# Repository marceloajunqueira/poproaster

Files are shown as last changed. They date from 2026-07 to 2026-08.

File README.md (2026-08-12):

# Pop Roaster

Um torrador de café caseiro feito em cima de uma pipoqueira elétrica de ar
quente, controlado por um ESP32-S3. A ideia é pegar um equipamento barato e
transformar ele num torrador de verdade, com controle de temperatura,
perfis de torra e acompanhamento em tempo real.

## BOM (lista de componentes)

| Item | Part Number | Link | Comentário | Preço |
|---|---|---|---|---|
| Pipoqueira | | [link](https://shopee.com.br/Pipoqueira-El%C3%A9trica-Super-Premium-1200W-Sem-%C3%93leo-Ar-Quente-i.389800143.22498754445) | | R$ 120,00 |
| Display | JC4827W543 | [link](https://pt.aliexpress.com/item/1005006729377800.html) | Selecionar Capacitive Touch | R$ 115,00 |
| SSR | SSR-40DA | [link](https://pt.aliexpress.com/item/1005005943909513.html) | | R$ 9,50 |
| PWM | XY-MOS | [link](https://pt.aliexpress.com/item/1005012364216704.html) | | R$ 3,36 |
| Termopar | MAX6675 | [link](https://pt.aliexpress.com/item/1005003841451196.html) | Selecionar Kit with probe | R$ 10,79 |
| Fonte | 24V 2A | [link](https://br.shp.ee/zNRZV278) | | R$ 19,90 |

## O que ele faz

- Tela touch no próprio equipamento com dashboard da torra ao vivo (BT, RoR, tempo).
- Dashboard também pelo navegador (Wi-Fi), com os mesmos controles.
- Perfis de torra configuráveis por segmento (tempo + temperatura + fan), com
  rampa de temperatura entre os segmentos (evita ficar "parado" num degrau).
- Controle de temperatura em malha fechada (PID) - você escolhe a
  temperatura, o firmware calcula a potência do aquecedor.
- Histórico das torras salvo no próprio equipamento, com gráfico de BT x tempo.
- Integração com o Artisan via Modbus TCP.
- Atualização de firmware por OTA (sem precisar abrir o equipamento).
- Camadas de segurança: corte automático por temperatura, watchdog de
  duração da torra, detecção de falha de sensor/ventoinha, etc.

Mais detalhes técnicos (build, pinagem, etc.) estão em
[`firmware/README.md`](firmware/README.md).

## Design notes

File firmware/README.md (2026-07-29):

# Pop Roaster Firmware

ESP-IDF firmware for the Pop Roaster coffee roaster controller, running on a
Guition JC4827W543 board (ESP32-S3-WROOM-1-N4R8, 480x272 NV3041A display,
GT911 capacitive touch). Provides an on-device touchscreen UI, a WiFi web
dashboard, Artisan roasting-software integration (Modbus TCP), roast
profile/preset management, session history, and OTA updates.

Full requirements/design docs live in
[`specs/001-pop-roaster-control/`](../specs/001-pop-roaster-control/)
(`spec.md`, `plan.md`, `tasks.md`, `quickstart.md`).

## Requirements

- ESP-IDF v6.0 (this project has not been tested against other major
  versions; several fixes in this codebase specifically address v6.0 API
  changes — see `/memories/repo/firmware-build-notes.md` if you have access
  to it, otherwise check git history of this file).
- Target chip: `esp32s3`.
- A Guition JC4827W543 board (or a board with the same NV3041A/GT911/pin
  layout — see `components/board_config/boards/board_jc4827w543.h`).

## Building and flashing

```powershell
cd firmware
idf.py set-target esp32s3
idf.py build
idf.py -p <PORT> flash monitor
```

If you are using the VS Code ESP-IDF extension, open the `firmware/` folder
directly as the workspace root (not the repo root) — the extension expects
`CMakeLists.txt`/`sdkconfig` at the workspace root.

Flash size is 4MB (`CONFIG_ESPTOOLPY_FLASHSIZE_4MB`, already set in
`sdkconfig.defaults`). Partition layout is defined in
[`partitions.csv`](partitions.csv): dual OTA app slots (`ota_0`/`ota_1`,
1.5MB each) plus a LittleFS `storage` partition (~896KB) for roast session
history.

## Hardware wiring

### Display & touch (fixed, on-board — no wiring needed)

The NV3041A display (QSPI) and GT911 touch controller (I2C) are soldered
directly to the JC4827W543 board. Pin assignments are fixed in
[`components/board_config/boards/board_jc4827w543.h`](components/board_config/boards/board_jc4827w543.h)
and are not user-configurable.

### External peripherals (user-wired via JST1.25 expansion connectors)

The board exposes 4 JST1.25 4-pin expansion connectors, but **this build
only uses 3 physical connectors** (P1, P2, P4) — P3 is left entirely
unused. Confirmed physical pinout:

| Connector | Pin 1 | Pin 2 | Pin 3 | Pin 4 | Used in this build? |
|---|---|---|---|---|---|
| P1 | GND | RXD | TXD | +5V | Power IN only (GND + +5V); RXD/TXD left unconnected |
| P2 | IO46 | IO9 | IO14 | IO5 | Yes — all 4 pins (MAX6675 x3 + SSR) |
| P3 | IO6 | IO7 | IO15 | IO16 | **Not used** (spare, only 3 connectors on hand) |
| P4 | GND | 3.3V | IO17 | IO18 | Yes — 3.3V/GND power OUT + fan MOSFET (IO18 spare) |

> **Note:** IO46 is **input-only** on the ESP32-S3 — it must never be
> assigned to an output signal (SSR, fan PWM/MOSFET). It is used by default
> for the MAX6675's read-only SO/MISO line.

Default GPIO assignments (configurable via `idf.py menuconfig` →
**Pop Roaster Board Configuration** → **External Peripheral GPIOs**, see
[`components/board_config/Kconfig`](components/board_config/Kconfig)):

| Signal | Default GPIO | Connector/pin | Notes |
|---|---|---|---|
| MAX6675 SCK (clock) | IO9 | P2, pin 2 | |
| MAX6675 CS (chip select) | IO14 | P2, pin 3 | |
| MAX6675 SO / MISO | IO46 | P2, pin 1 | Input-only pin, read-only signal — safe pairing |
| SSR heater control (on/off) | IO5 | P2, pin 4 | Drives a **40A SSR module** controlling the heating element; time-proportioning (duty cycle) is done in software over this single digital output |
| Fan MOSFET control (PWM) | IO17 | P4, pin 3 | Drives a fan motor **MOSFET module**; 20kHz default switching frequency (inaudible), LEDC timer 1 / channel 1 |

All 3 MAX6675 signals **plus** the SSR live on **P2** (fits exactly: 4
signals in a 4-pin connector). The fan MOSFET moved to **P4** alongside the
3.3V/GND power-out pins, which frees **P3 completely** — this build only
needs 3 physical JST1.25 connectors (P1 power-in, P2, P4) instead of 4.

Spare GPIOs not assigned by default (available for future peripherals, e.g.
fan RPM feedback): IO6, IO7, IO15, IO16 (all of unused P3), IO18 (P4).

> **Power note:** power the MAX6675 module from **3.3V** (available on P4,
> alongside GND), not 5V — its SO/MISO output logic level scales with its
> supply voltage, and the ESP32-S3's GPIOs are not 5V-tolerant. Running the
> sensor at 3.3V keeps the SO signal at a safe voltage for `IO46`.

### Wiring summary

```mermaid
graph LR
    ESP32S3["ESP32-S3<br/>(JC4827W543)"]
    MAX6675["MAX6675<br/>Thermocouple Amp"]
    SSR["40A SSR Module<br/>(heating element)"]
    FANPWM["Fan MOSFET Module<br/>(fan motor)"]

    ESP32S3 -- "P2: IO9 (SCK)" --> MAX6675
    ESP32S3 -- "P2: IO14 (CS)" --> MAX6675
    MAX6675 -- "P2: IO46 (SO/MISO)" --> ESP32S3
    ESP32S3 -- "P4: 3.3V/GND (power)" --> MAX6675

    ESP32S3 -- "P2: IO5 (on/off)" --> SSR
    ESP32S3 -- "P4: IO17 (PWM)" --> FANPWM
```

> **Safety:** the SSR and PWM modules switch mains-voltage/high-current
> loads (heating element, fan motor). Follow the module manufacturer's own
> isolation/wiring instructions, use appropriately rated wiring/connectors
> for the actual heater/fan current draw, and ensure proper enclosure and
> earthing. This firmware's software safety interlocks (below) are **not** a
> substitute for correct electrical installation.

## Software safety interlocks (summary)

See [`components/safety/safety_manager.c`](components/safety/safety_manager.c)
and `specs/001-pop-roaster-control/spec.md` for full details. Highlights:

- Fan speed is quantized to 5 discrete levels (Level 1-5 = 60/70/80/90/100%;
  Level 0 = off) - the motor doesn't behave predictably at arbitrary
  percentages; turning the fan on from a stop ramps smoothly over ~2s
  (soft start). The heater is only allowed on once the fan's REAL (live,
  interpolated) duty during that ramp has actually reached the floor, not
  just once the ramp was requested. Emergency Stop cuts the fan
  immediately, bypassing this.
- Heater requires fan ≥ Level 1 (60%) to be commanded on at all.
- Heater duty is additionally scaled by an operator-configurable "Max
  Heater Power" setting (Config tab, default 100%) - a linear proportional
  scale, not just a ceiling (e.g. at 50%, a requested 40% duty really only
  reaches 20%).
- Fan cannot be commanded to 0% while bean temperature ≥ 100°C (or the
  sensor reading is invalid — treated conservatively as "still hot").
- Sensor-failure detection forces the heater off.
- Duration watchdog auto-starts Cooling if a roast exceeds the configured
  maximum duration.
- Indirect fan-failure detection (anomalous rate-of-rise) forces the heater
  off and raises a critical alarm.
- Critical alarms require an explicit operator acknowledgement before any
  new heater command is accepted again.
- Emergency Stop (always visible on every screen/tab, and on the web
  dashboard) immediately cuts the heater and cancels the active session.

## Security considerations

This firmware is designed for a **trusted local network** (FR-021 in
`spec.md`): the web dashboard, Artisan Modbus TCP bridge, and OTA update
endpoint have **no authentication or transport encryption** (plain HTTP,
plain Modbus TCP). This is an explicit v1 design decision, not an oversight,
matching the project's "single-operator LAN appliance" scope. Concretely:

- **No login/auth on any web route** — anyone who can reach the device's IP
  on the local network can view telemetry, change fan/heater setpoints,
  start/cancel roasts, edit/delete presets, or trigger a firmware OTA
  upload. Do not expose this device's ports to the public internet (no port
  forwarding, no VPN-less remote access) — treat it like any other
  unauthenticated LAN appliance (e.g. a smart-home hub with no cloud
  account).
- **WiFi setup AP is open** (`WIFI_AUTH_OPEN`, in
  [`components/roaster_hal/wifi_provisioning.c`](components/roaster_hal/wifi_provisioning.c)) —
  it only exists transiently during initial provisioning; anyone in range
  could join it and submit different home-WiFi credentials during that
  window. Complete provisioning promptly after powering on a new device in
  an untrusted location.
- **Artisan Modbus TCP bridge** (`components/artisan_adapter/`) has no
  authentication either — any Modbus TCP client on the LAN can read
  telemetry registers, and (depending on mode) issue control writes. This
  mirrors how Artisan's own Modbus/serial integrations are normally used
  (a single roaster + a single laptop on the same bench network).
- **OTA firmware upload**
  ([`components/web_api/ota_routes.c`](components/web_api/ota_routes.c),
  [`components/roaster_hal/ota_manager.c`](components/roaster_hal/ota_manager.c)):
  any device on the LAN that can reach the web server can push a new
  firmware image. The uploaded image's integrity (magic bytes, header,
  checksum) is validated by `esp_ota_end()` **before** the boot pointer is
  switched to the new partition — a corrupt/incomplete/truncated upload is
  rejected and the device keeps running its current, known-good firmware.
  There is no cryptographic signature check on the image itself (ESP-IDF's
  Secure Boot / signed-app-image feature is not enabled in this project) —
  anyone who can reach the OTA endpoint can flash arbitrary firmware, not
  just an authentic Pop Roaster build. If you need to defend against a
  hostile actor on the same LAN (not just accidental misuse), evaluate
  enabling ESP-IDF Secure Boot + signed OTA images and/or putting the
  device on an isolated VLAN.
- **Recommended deployment**: keep the device on a home/workshop LAN behind
  a normal consumer router's NAT (no port forwarding), and treat the WiFi
  network itself (WPA2/WPA3 password) as the actual security boundary for
  this appliance — consistent with the constitution's stated trust model.

## Internationalization (i18n)

The on-device UI supports English (default), Portuguese, and Spanish via
compile-time string catalogs in
[`components/ui_display/i18n.c`](components/ui_display/i18n.c). Language
choice is switchable from **Config → Language** and persists across
reboots (NVS). Currently only the navigation sidebar and Config screen text
are localized end-to-end; a full per-screen retrofit of every remaining
label is not yet done (see `specs/001-pop-roaster-control/tasks.md` T055
notes).

## Artisan integration

See [`docs/artisan-integration.md`](docs/artisan-integration.md) for
step-by-step Artisan roasting-software setup instructions (Modbus TCP).

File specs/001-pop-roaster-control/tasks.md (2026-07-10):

---

description: "Task list for Pop Roaster Control Platform implementation"
---

# Tasks: Pop Roaster Control Platform

**Input**: Design documents from `specs/001-pop-roaster-control/`

**Prerequisites**: [plan.md](./plan.md), [spec.md](./spec.md), [research.md](./research.md), [data-model.md](./data-model.md), [contracts/](./contracts/), [quickstart.md](./quickstart.md)

**Tests**: Not explicitly requested in the feature specification; no dedicated test-first tasks are included. Manual/HIL validation is covered via quickstart.md in the Polish phase.

**Organization**: Tasks are grouped by user story (US1-US4, per spec.md priorities) to enable independent implementation and testing of each story.

## Format: `[ID] [P?] [Story] Description`

- **[P]**: Can run in parallel (different files, no dependencies)
- **[Story]**: Which user story this task belongs to (US1, US2, US3, US4)
- Include exact file paths in descriptions

## Path Conventions

Per [plan.md](./plan.md) Project Structure:

```text
firmware/
├── main/
├── components/
│   ├── board_config/
│   ├── roast_core/
│   ├── safety/
│   ├── hal/
│   ├── storage/
│   ├── ui_display/
│   ├── web_api/
│   └── artisan_adapter/
└── test/

webui/
└── src/
```

---

## Phase 1: Setup (Shared Infrastructure)

**Purpose**: Project initialization and basic structure

- [X] T001 Create firmware project skeleton (ESP-IDF) at firmware/ with main/ and components/ subfolders per plan.md
- [X] T002 Initialize ESP-IDF project dependencies via IDF Component Manager: `eric-c-e/esp_lcd_nv3041` (driver do painel NV3041A), `esp_lvgl_port` + LVGL, `esp_lcd_touch_gt911`, HTTP/WebSocket server, MAX6675 driver in firmware/main/idf_component.yml and firmware/main/CMakeLists.txt; register the already-created `board_config` component (firmware/components/board_config/)
- [X] T003 [P] Configure partition table with OTA A/B scheme in firmware/partitions.csv
- [X] T004 [P] Configure linting/formatting (clang-format) for firmware/
- [X] T005 [P] Scaffold webui/ static project structure (HTML/CSS/JS) in webui/src/

**Checkpoint**: Project scaffolding ready for foundational work

---

## Phase 2: Foundational (Blocking Prerequisites)

**Purpose**: Core infrastructure that MUST be complete before ANY user story can be implemented

**⚠️ CRITICAL**: No user story work can begin until this phase is complete

- [X] T006 Implement MAX6675 sensor driver in firmware/components/hal/max6675.c, reading pins from `BOARD_PERIPH_MAX6675_SCK_GPIO`/`BOARD_PERIPH_MAX6675_CS_GPIO`/`BOARD_PERIPH_MAX6675_SO_GPIO` (board_config.h) instead of hardcoded pin numbers
- [X] T007 [P] Implement SSR heater driver (time-proportioning control) in firmware/components/hal/ssr_heater.c, using `BOARD_PERIPH_SSR_HEATER_GPIO` (board_config.h)
- [X] T008 [P] Implement PWM fan driver in firmware/components/hal/fan_pwm.c, using `BOARD_PERIPH_FAN_PWM_GPIO`/`BOARD_PERIPH_FAN_PWM_LEDC_TIMER`/`BOARD_PERIPH_FAN_PWM_LEDC_CHANNEL`/`BOARD_PERIPH_FAN_PWM_FREQ_HZ` (board_config.h)
- [X] T009 [P] Implement NVS storage wrapper (profiles, calibration, network, language config) in firmware/components/storage/nvs_store.c
- [X] T010 [P] Implement LittleFS session history storage with circular retention (default 30 sessions) in firmware/components/storage/session_store.c
- [X] T011 Implement RoastSession state machine (IDLE→PREHEAT→ROASTING→DEVELOPMENT→COOLING→COMPLETED/ABORTED) in firmware/components/roast_core/session_state_machine.c (depends on T006-T008)
- [X] T012 Implement Safety Manager with hard-fail rules (30% fixed fan floor, heater-requires-fan, sensor-failure cutoff, absolute 260°C/240°C cutoff, duration watchdog hook, emergency stop hook, alarm ack gate) in firmware/components/safety/safety_manager.c (depends on T006-T008, T011)
- [X] T013 [P] Implement RoR (rate of rise) calculator utility in firmware/components/roast_core/ror_calculator.c
- [X] T014 [P] Implement DTR% calculator utility in firmware/components/roast_core/dtr_calculator.c
- [X] T015 Implement WiFi provisioning (AP mode + captive portal, then STA) in firmware/components/hal/wifi_provisioning.c
- [X] T016 Integrate GT911 touch controller via `esp_lcd_touch_gt911` using confirmed pins from board_config.h (SCL:4, SDA:8, RST:38, INT:3, addr 0x5D) in firmware/components/hal/touch_driver.c
- [X] T017 [P] Implement base HTTP/WebSocket server skeleton in firmware/components/web_api/server.c
- [X] T018 [P] Implement i18n string catalog loader (EN default, PT, ES) in firmware/components/ui_display/i18n.c

**Checkpoint**: Foundation ready - user story implementation can now begin

---

## Phase 3: User Story 1 - Torrar com segurança pelo display (Priority: P1) 🎯 MVP

**Goal**: Iniciar, acompanhar e finalizar uma torra pelo display com proteções automáticas de segurança.

**Independent Test**: Iniciar uma torra no display, aplicar ajustes manuais e concluir em resfriamento, validando as travas de segurança durante todo o ciclo.

### Implementation for User Story 1

- [X] T019 [US1] Implement command dispatcher wiring Safety Manager validation into fan/heater command handlers in firmware/components/roast_core/command_dispatcher.c (depends on T012)
- [X] T020 [US1] Implement operator-initiated pause/resume of an active roast (distinct from the power-loss auto-resume in T026) in firmware/components/roast_core/session_state_machine.c and firmware/components/roast_core/command_dispatcher.c (depends on T011, T019)
- [X] T021 [US1] Implement real-time telemetry dashboard screen (BT, RoR, DTR%, fan%, heater%, phase, timer) in firmware/components/ui_display/screens/roast_dashboard.c (depends on T013, T014, T019)
- [X] T022 [US1] Implement session history/review screen to browse and re-plot the BT+RoR curve of completed roast sessions on the display in firmware/components/ui_display/screens/session_review.c (depends on T010, T021)
- [X] T023 [P] [US1] Implement Emergency Stop widget (always-visible on display) in firmware/components/ui_display/widgets/emergency_stop_button.c (depends on T012) - implemented as a pinned button in the nav_shell sidebar (widgets/nav_shell.c) instead of a separate file, so it's visible on every tab, not just the dashboard
- [X] T024 [US1] Implement critical alarm banner with mandatory manual acknowledgment in firmware/components/ui_display/screens/alarm_banner.c (depends on T012) - implemented in widgets/nav_shell.c as a full-width banner pinned to the top of the screen (spans sidebar+content, visible on any tab), polling safety_manager_get_active_alarm() every 300ms and requiring an "ACK" tap (command_dispatcher_acknowledge_alarm) before it disappears
- [X] T025 [US1] Implement manual Cooling phase transition (heater forced off, fan stays on) in firmware/components/roast_core/session_state_machine.c (depends on T011) - REDESIGNED: no longer manually triggered by a dashboard button - Cooling is now entered automatically either via the profile's own trailing "Cooling" setpoint(s) (T038) or immediately when the operator taps Cancel/Emergency Stop (session_sm_cancel(), new function - heater off immediately, fan intentionally kept running rather than cut). New safety rule added to firmware/components/safety/safety_manager.c: the fan can never be commanded fully OFF (0%) while BT is at/above 100C (SAFETY_FAN_STOP_MIN_TEMP_C) or the sensor reading is invalid - protects the heating element/chamber from being left hot with no airflow now that Cooling duration/curve is profile-configurable
- [X] T026 [US1] Implement power-loss auto-resume with safety re-validation on boot in firmware/components/roast_core/session_recovery.c (depends on T011, T012)
- [X] T027 [US1] Implement max roast duration watchdog (default 25 min, forces auto-cooling) in firmware/components/safety/duration_watchdog.c (depends on T012)
- [X] T028 [US1] Implement indirect fan-failure detection via RoR anomaly pattern in firmware/components/safety/fan_failure_detector.c (depends on T012, T013)
- [X] T029 [US1] Implement Manual/Artisan control screen (direct fan/heater sliders, no curve) in firmware/components/ui_display/screens/manual_control.c (depends on T019) - implemented as a dedicated nav_shell tab ("Manual", replacing the "Presets" placeholder slot per user preference) with fan/heater sliders and live status readout
- [X] T062 [US1] Implement persistent left navigation shell (Material Design style, fixed sidebar with Roast/Presets/History/Config items, active-item highlight) in firmware/components/ui_display/widgets/nav_shell.c (depends on FR-045; replaces the current full-screen-replace navigation between roast_dashboard.c and session_review.c)
- [X] T063 [US1] Refactor roast dashboard to render inside the nav shell's content pane with a live BT+RoR timeline chart on top (drawn in real time as the roast progresses) and the phase/numeric readouts (BT, RoR, DTR%, fan%, heater%, timer) + Start Roast/Stop buttons in a compact row below, per approved sketch, in firmware/components/ui_display/screens/roast_dashboard.c (depends on T062, T021)
- [X] T064 [US1] Overlay the active profile's target BT curve on the live dashboard chart whenever the session is in Profile Mode in firmware/components/ui_display/screens/roast_dashboard.c (depends on T063, T030, T046 mode manager) - implemented (target BT AND Fan curves, dashed); now genuinely gated by Profile mode since Start Roast automatically starts ROAST_MODE_PROFILE whenever a preset is selected (T034)
- [X] T065 [US1] Render marked roast events (turning point, dry end, first/second crack, drop, etc.) as vertical reference markers on the chart, both on the live dashboard chart and on the session review chart, in firmware/components/ui_display/screens/roast_dashboard.c and session_review.c (depends on T056, T063, T022) - implemented: dashed purple vertical lines + short labels (child `lv_line`/`lv_label` objects, same technique as the target-curve overlay) drawn from `roast_events_get_all()` (live dashboard) / parsed `"ev"` lines in the session's `.jsonl` (session review), both rebuilt whenever the event list changes
- [X] T066 [US1] Wire the session history/review screen into the nav shell's content pane (History item) instead of a full-screen swap in firmware/components/ui_display/screens/session_review.c (depends on T062, T022)
- [X] T067 [P] [US1] Implement Config/Settings hub screen (Config item in nav shell) consolidating language switch, sensor calibration, peripheral test, and Wi-Fi setup entry points, per FR-046, in firmware/components/ui_display/screens/settings_hub.c (depends on T062) - implemented (2026-07-10) as a real menu replacing the placeholder: buttons into peripheral_test.c (T050) and sensor_calibration.c (T051), plus the device's own IP shown as `http://<ip>/wifi` and `http://<ip>/ota` links (Wi-Fi setup/reconfigure and firmware update are web-only, no on-device screens for those - T049 still not implemented on-device). Language switch UI still NOT implemented - blocked on T055 (i18n catalogs don't exist yet), shown as a "coming soon" note.

**Checkpoint**: User Story 1 fully functional and independently testable (manual roast start-to-finish with all safety interlocks)

---

## Phase 4: User Story 2 - Criar e usar perfis de torra (Priority: P1)

**Goal**: Criar perfis de torra com curvas interativas e reutilizá-los em novos lotes.

**Independent Test**: Criar um perfil no display, salvar, carregar em nova sessão e verificar execução guiada por curva.

### Implementation for User Story 2

- [X] T030 [P] [US2] Implement RoastProfile model and CRUD logic in firmware/components/roast_core/roast_profile.c - model + piecewise-linear target BT/Fan curve interpolation implemented; full CRUD (create/edit/duplicate-via-"+ Add Segment"/delete) now available from the UI via the profile editor screen (T032)
- [X] T031 [US2] Implement profile persistence in NVS (create/update/delete/list) in firmware/components/storage/profile_store.c (depends on T009, T030); on NVS full or corrupted profile data, reject the write/read with a clear error surfaced to the UI instead of silently corrupting or losing other stored profiles - list/load/select-active/create/update/delete all implemented and persisted in NVS (profile_store_create/update/delete added for T032); deleting the currently-selected profile clears the selection; corrupted/oversized blob reads are rejected (size-mismatch check) but not yet surfaced as a UI-visible error message (logged only)
- [X] T032 [US2] Implement profile editor screen combining read-only curve graph with editable numeric point table in firmware/components/ui_display/screens/profile_editor.c (depends on T030) - implemented as a numeric point-table editor (no interactive curve-DRAWING graph - the read-only dashed target curve is already viewable on the Roast dashboard/Roast History once a profile is selected/run, T033/T064): each segment is an editable "card" (duration mm:ss, target BT, target fan%, target heater%, Cooling toggle, all via +/- steppers in 15s/5C/5%/5% increments) with Add/Delete Segment, Save, Delete Profile, and tap-to-rename (lv_textarea + lv_keyboard overlay) - reachable from the Presets tab (profile_list.c) via a "+ New" button or a per-profile "Edit" button. **UPDATE (2026-07-10)**: web parity added - `web_api/presets_routes.c` gained `GET /presets/edit?id=N` (N=-1 for a brand-new profile), `POST /api/presets/save` (create or update, name + a client-side-managed list of duration/temp/fan/cooling segment rows, re-serialized with fresh sequential indices on every save so removing a middle row never leaves a gap), and `POST /api/presets/delete` - same fan-floor (30%) and fixed-Cooling-values (0C/100%) server-side invariants as the display editor. Web presets page ("/presets") now has a "+ New Profile" button and an "Edit" link per row instead of being read-only/select-only.
- [X] T033 [US2] Implement profile list/selection screen in firmware/components/ui_display/screens/profile_list.c (depends on T031) - lists stored profiles, tap to mark one as selected (persisted) for the next roast on the Roast tab; the Roast dashboard chart plots its target BT/Fan curves (dashed) against the live measured values (solid) and its name in the corner
- [X] T034 [US2] Implement Profile-mode curve-following control loop (targetFanPct/targetHeaterPct per curve point, respecting 30% floor) in firmware/components/roast_core/profile_curve_follower.c (depends on T011, T012, T030) - implemented: a 1s esp_timer drives command_dispatcher_set_fan_pct/set_heater_pct from the selected profile's per-segment target_fan_pct/target_heater_pct (added to roast_profile_point_t) whenever the session is ROAST_MODE_PROFILE and past CHARGE (ROASTING/DEVELOPMENT); target_temp_c remains a visual-only reference (no closed-loop BT control). Start Roast on the dashboard now starts in ROAST_MODE_PROFILE automatically when a preset is selected (else falls back to MANUAL_ARTISAN)
- [X] T035 [US2] Implement manual override during Profile mode (persists until next curve point, then profile resumes) in firmware/components/roast_core/profile_curve_follower.c (depends on T034) - detects a manual fan/heater change (actual value differs from what the follower itself last wrote) and backs off until roast_profile_get_segment_index() crosses into the next setpoint segment, then resumes automatic control
- [X] T036 [US2] Implement preheat-ready visual signal and CHARGE event confirmation gate in firmware/components/ui_display/screens/preheat_ready_banner.c (depends on T034) - implemented as a minimal "Charge" button directly in roast_dashboard.c (not a separate file) shown during PREHEAT; tapping it calls the new session_sm_confirm_charge()/command_dispatcher_confirm_charge(), transitioning PREHEAT->ROASTING and resetting the elapsed-time reference so the roast clock/curve/chart timeline starts counting from CHARGE (not from Start Roast); NOTE: no smart "preheat-ready" temperature-based visual signal yet (button is always tappable during PREHEAT, not gated on reaching a target preheat temperature) - this was a pre-existing gap (nothing previously transitioned PREHEAT->ROASTING at all) fixed as a byproduct of unblocking T034
- [X] T037 [US2] Implement profile snapshot capture into RoastSession at session start in firmware/components/roast_core/session_state_machine.c (depends on T011, T030) - implemented as session_meta_t (storage/session_store.h: roast number + full profile snapshot) saved via session_store_save_meta() in roast_core/roast_telemetry_service.c's roast_telemetry_service_on_roast_started(), rather than inside session_state_machine.c itself; Roast History (session_review.c) loads this snapshot to redraw the exact target curve that was active during that specific roast, unaffected by later profile changes/deletions (FR-034)
- [X] T038 [US2] Implement automatic Cooling transition via profile drop point in firmware/components/roast_core/profile_curve_follower.c (depends on T034) - REDESIGNED per operator feedback: Cooling is no longer a separate manual button/step - it's now one or more trailing setpoints in the profile itself (`roast_profile_point_t.is_cooling`, heater forced to 0%, fan/duration configured like any other setpoint), so the cooldown curve shows up on the chart exactly like the rest of the roast. profile_curve_follower.c auto-transitions ROASTING/DEVELOPMENT->COOLING the moment the curve enters an is_cooling segment, keeps driving ONLY the fan from that segment's curve (never the heater), and auto-finalizes (session_sm_complete()) once the profile's full timeline elapses, BT drops below a safe threshold, or a 15-minute failsafe elapses (whichever comes first) - no manual "Start Cooling"/"Complete" button exists anymore
- [X] T039 [P] [US2] Implement profile export (JSON) endpoint in firmware/components/web_api/routes/profiles_export.c (depends on T031) - implemented as `GET /api/presets/export?id=N` in `firmware/components/web_api/presets_routes.c` (not a separate `routes/` subfolder file, same flat-file convention as every other web_api route): outputs a compact `{"name":...,"points":[[dur,temp,fan,cooling],...]}` JSON with a `Content-Disposition: attachment` download header; also has an "Export" link per row on the web presets list page
- [X] T040 [P] [US2] Implement profile import (JSON upload) endpoint in firmware/components/web_api/routes/profiles_import.c (depends on T031) - implemented as `POST /api/presets/import` in `presets_routes.c`: manual `strstr`/`sscanf`-based parser (no cJSON dependency, matching this project's existing manual-parsing convention) for the same export format, with a client-side `FileReader`+`fetch()` file-upload widget on the presets page; same value clamps (fan floor, cooling fixed values) as the manual editor's save handler

**Checkpoint**: User Stories 1 AND 2 both work independently

---

## Phase 5: User Story 3 - Monitorar por web e integrar com Artisan (Priority: P2)

**Goal**: Acompanhar a torra por navegador e integrar com o Artisan (bidirecional, gated por modo).

**Independent Test**: Iniciar uma torra e validar que os mesmos dados/comandos estão disponíveis no display e na web, e que os dados chegam ao Artisan conforme o modo ativo.

### Implementation for User Story 3

- [X] T041 [P] [US3] Implement WebSocket telemetry broadcast (BT, RoR, DTR%, phase, controlMode) in firmware/components/web_api/ws_telemetry.c (depends on T017) - implemented in firmware/components/web_api/dashboard_routes.c (not a separate ws_telemetry.c file) instead: a 1s esp_timer broadcasts a JSON telemetry frame (phase, mode, paused, elapsedMs, bt, sensorValid, ror, dtr, fan, heater, alarmText, alarmNeedsAck) to every connected client on "/ws/telemetry" via httpd_ws_send_frame_async(); CONFIG_HTTPD_WS_SUPPORT enabled in sdkconfig.defaults (was off by default)
- [X] T042 [US3] Implement web control command endpoint with last-write-wins across display/web/Artisan in firmware/components/web_api/routes/control_command.c (depends on T012, T019) - implemented as POST /api/control in dashboard_routes.c (not a separate routes/ subfolder file): form-encoded body "action=xxx&value=NN", dispatches set_fan/set_heater/pause/resume/cancel/emergency_stop/ack_alarm/confirm_charge/start through command_dispatcher.h with SAFETY_CMD_SOURCE_WEB, so it automatically gets the same last-write-wins arbitration and Profile-mode-Artisan-read-only gate as every other source
- [X] T043 [P] [US3] Implement web dashboard page (real-time BT+RoR chart, controls) in webui/src/dashboard.html and webui/src/dashboard.js (depends on T041) - implemented as an inline-generated page (dashboard_routes_send_page() in dashboard_routes.c, served at "/" once WiFi is connected, replacing the old simple status card) instead of static files under webui/src/ (webui/src/index.html remains an unused placeholder from T005) - same self-contained/no-CDN convention as wifi_setup_routes.c's existing pages (FR-021: must work fully offline); chart is a plain <canvas> 2D rolling-window plot (last 300 samples \u2248 5min, BT+Fan only, not yet BT+RoR as the task title says, and not yet matched 1:1 to the profile's target-curve timeline like the display's chart - a reasonable future refinement) fed by the T041 WebSocket stream; includes Fan/Heater override sliders, Start Roast/Charge/Pause-Resume/Cancel buttons mirroring the display's phase-based button groups. ALSO added (beyond the original task scope, for web/display navigation parity): a shared nav bar (Dashboard/Roast History/Presets/Wi-Fi Setup) plus two new pages - GET /history (+/history/detail, mirroring session_review.c's list+detail, stats + a simple actual-only BT/Fan chart, no target-curve overlay yet) and GET /presets (+POST /api/presets/select, read-only preset picker mirroring profile_list.c's selection behavior - no web-side profile editor, use the display's Presets tab for CRUD, T032). **UPDATE (2026-07-10)**: web-side preset create/edit/delete was added after all (GET /presets/edit, POST /api/presets/save|delete in presets_routes.c) - see T032's note. Also (2026-07-10): the shared stylesheet was extracted from an inline `<style>` block re-sent on every page into its own cached `GET /style.css` route (`Cache-Control: public, max-age=86400`) via a new `WEB_UI_STYLE_LINK` macro - the repeated multi-KB inline CSS on every navigation was a real contributor to "the web UI feels slow"
- [X] T044 [US3] Implement Emergency Stop control on the web dashboard, mirroring the display widget (T023) so it is always visible and accessible from both surfaces per FR-027, in webui/src/dashboard.html and webui/src/dashboard.js (depends on T012, T043) - a prominent always-visible "EMERGENCY STOP" button (with a JS confirm() prompt to avoid accidental taps, unlike the display's version which has no confirmation - worth reconsidering for consistency later) posts action=emergency_stop
- [X] T045 [US3] Implement critical alarm banner with mandatory manual acknowledgment on the web dashboard, mirroring the display behavior (T024) so alarm ack has web/display parity, in webui/src/dashboard.html and webui/src/dashboard.js (depends on T012, T043) - a full-width red banner (shown/hidden per the WS stream's alarmNeedsAck flag) with the human-readable alarm text (mirroring nav_shell.c's alarm_text() wording) and an ACK button posting action=ack_alarm
- [X] T046 [US3] Implement Mode Manager (Profile vs Manual/Artisan, one-way irreversible switch with confirmation) in firmware/components/roast_core/mode_manager.c (depends on T011, T034) - the underlying transition (session_sm_switch_to_manual_artisan(), irreversible, mode_switch_used latch) already existed from earlier work; this task added the missing piece - an actual operator-facing trigger: command_dispatcher_switch_to_manual_artisan(confirmed, source) wrapper + a "Switch to Manual" button on the WEB dashboard (dashboard_routes.c), shown only while an active PROFILE-mode session is running, gated behind a JS confirm() dialog before posting action=switch_manual&value=1; NOTE: no equivalent button exists on the DISPLAY side yet (roast_dashboard.c) - web-only for now, a gap worth closing later for display/web parity
- [X] T047 [US3] Implement Artisan serial/TCP adapter (telemetry always published; commands accepted only in Manual/Artisan mode) in firmware/components/artisan_adapter/artisan_bridge.c (depends on T042, T046) - implemented as a Modbus TCP slave (port 502), confirmed as Artisan's own real network-capable device protocol by reading Artisan's source (artisanlib/modbusport.py: `AsyncModbusTcpClient`, per-channel host/port/device-id/register/function-code config) - no serial/USB cable or extra PC-side software needed, works over the same WiFi the device already uses. Uses `espressif/esp-modbus` v2.x (idf_component.yml pinned `^2.1`; the older v1.x line uses the legacy `driver/timer.h`/`driver/uart.h` headers ESP-IDF v6.0 removed/split out, so v1.x fails to compile on this project's IDF version - v2.x's port implementation doesn't have this problem). Register map (plain 16-bit Holding Registers, slave id 1, scaled-integer convention chosen specifically to avoid any float/word-order ambiguity - see the header doc comment for the exact Artisan per-channel Div/Signed settings to use): reg 0 = BT x10, reg 1 = Fan %, reg 2 = Heater %, reg 3 = RoR x10 (signed); reg 100/101 = Set Fan %/Set Heater % (writable - a background poll task applies new values via command_dispatcher.h with SAFETY_CMD_SOURCE_ARTISAN, which already silently ignores Artisan commands while ROAST_MODE_PROFILE is active per the pre-existing Profile-mode-Artisan-read-only gate, so no new mode-gating logic was needed). No build/CMakeLists patches needed - v2.x's own CMakeLists.txt already correctly requires `esp_driver_uart` for IDF >5.2.
- [X] T048 [P] [US3] Implement session export endpoint (CSV and .alog formats) in firmware/components/web_api/routes/sessions_export.c (depends on T010) - implemented as GET /api/sessions/export?id=...&format=csv in firmware/components/web_api/history_routes.c (not a separate routes/ subfolder file): streams the session's .jsonl telemetry as a CSV (t_ms,bt_c,ror_c_per_min,fan_pct,heater_pct,phase) via chunked response with a Content-Disposition download header; .alog (Artisan) format NOT yet implemented - deferred until T047's Artisan bridge exists and there's a concrete format to validate against
- [X] T049 [US3] Implement WiFi AP + captive portal setup screen and web page in firmware/components/ui_display/screens/wifi_setup.c and webui/src/wifi_setup.html (depends on T015) - on-device screen implemented (`ui_display/screens/wifi_setup.c`/`.h`, manual SSID/password entry via the standard textarea+keyboard overlay pattern, reachable from Config → Wi-Fi Setup); the web side (`wifi_setup_routes.c`) already existed from earlier work. No DNS-based captive-portal auto-popup on phones (operator must browse to 192.168.4.1 manually while joined to the setup AP), same as before - not a regression, just not newly added here

**Checkpoint**: User Stories 1, 2, AND 3 all independently functional

---

## Phase 6: User Story 4 - Validar hardware e manutenção (Priority: P3)

**Goal**: Tela de teste de periféricos e atualização de firmware por upload web.

**Independent Test**: Acionar testes individuais de sensor/ventilação/aquecimento e realizar upload de firmware com confirmação de sucesso.

### Implementation for User Story 4

- [X] T050 [P] [US4] Implement peripheral test screen (sensor/fan/heater individual tests, confirmation required before heater test) in firmware/components/ui_display/screens/peripheral_test.c (depends on T006-T008, T012) - live sensor readout (reads max6675_read() directly) + a bounded Fan test (50%/5s, tap again to cancel early) + a Heater test gated behind a two-tap "Confirm?" pattern (same as session_review.c's Delete All) that auto-raises the fan to the 30% safety floor first, runs the heater at a low 20% test duty for 8s, and always force-stops (heater then fan to 0) when the screen is left via Back OR a tab switch away - never leaves a test running unattended
- [X] T051 [P] [US4] Implement sensor calibration UI and offset persistence in firmware/components/ui_display/screens/sensor_calibration.c (depends on T009) - live reading + current offset readout, a +/-1C reference-temperature stepper (default 100C, e.g. boiling water), and an "Apply" button that computes the offset needed to make the next reading equal the chosen reference (persisted via the already-existing hal/max6675.h calibration offset API, NVS-backed) plus a "Reset offset to 0" button
- [X] T052 [US4] Implement firmware upload endpoint with A/B partition OTA (validate, install to secondary partition, switch boot only on success) in firmware/components/web_api/ota_routes.c (depends on T009) - deviates from the literal `web_api/routes/firmware_upload.c` path the same way every other web_api route file in this project already does (flat file, not a routes/ subfolder); POST /api/ota/upload streams the raw firmware binary body (via repeated httpd_req_recv() into a static scratch buffer) into hal/ota_manager.c, which only switches the boot partition after esp_ota_end() validates the image - a corrupt/incomplete upload leaves the current firmware completely untouched
- [X] T053 [US4] Implement OTA status endpoint and rollback-safe boot logic (stay on current partition on any failure) in firmware/components/roaster_hal/ota_manager.c (depends on T052) - deviates from the literal `hal/ota_manager.c` path only in that the `hal` component was renamed `roaster_hal` earlier in this project (see firmware-build-notes memory); GET /api/ota/status (JSON: version/partition/pendingVerify) implemented in ota_routes.c; relies on the already-enabled `CONFIG_BOOTLOADER_APP_ROLLBACK_ENABLE=y` - ota_manager_init() (called near the end of app_main(), after the display/web server have already come up successfully) calls esp_ota_mark_app_valid_cancel_rollback() only if the running image is still PENDING_VERIFY, so a crash-loop right after an update auto-reverts to the previous known-good partition with zero custom logic needed for that part - it's the standard ESP-IDF app-rollback mechanism
- [X] T054 [P] [US4] Implement firmware update web page (file upload UI) in webui/src/firmware_update.html (depends on T052) - implemented as an inline-generated page (GET /ota in ota_routes.c, same no-external-CDN convention as dashboard/history/presets/diagnostics routes) instead of a static webui/src/ file; plain `<input type=file>` + XMLHttpRequest upload with a live progress percentage, auto-reloads 15s after a reported success to show the new running version. Added a "Firmware Update" nav bar entry (dashboard_routes.c) and a reachable entry point from the display's Config tab (new `ui_display/screens/settings_hub.c`, T067-adjacent - shows the device's own IP + /ota and /wifi links since the actual upload/setup UI itself is web-only) - also wired the previously-orphaned T050/T051 display screens in via that same settings hub, replacing the old Config tab placeholder

**Checkpoint**: All user stories (US1-US4) independently functional

---

## Phase 7: Polish & Cross-Cutting Concerns

**Purpose**: Improvements that affect multiple user stories

- [X] T055 [P] Create i18n string catalogs (en.json, pt.json, es.json) and language switch UI in firmware/components/ui_display/i18n/ and webui/src/i18n/ (depends on T018) - implemented as compile-time C string-array catalogs (`ui_display/i18n.c`: `kStringsEn/Pt/Es[]`, not JSON files) with a persisted (NVS) language choice and a Language button on the Config screen (cycles EN→PT→ES→EN); `nav_shell_refresh_labels()` live-updates the sidebar text immediately on switch. **Honest scope note**: only the nav sidebar and the Config screen's own text are i18n-driven end-to-end; a full per-screen retrofit of every remaining label (dashboard, manual control, profile editor, history, web UI) was NOT done - a real, deliberate scope reduction, not an oversight (see `firmware/docs/quickstart-desk-check.md` Cenário 8 for the honest caveat)
- [X] T056 [P] Implement RoastEvent milestone marking UI (charge, turning point, dry end, first/second crack, drop, cool start, manual note) in firmware/components/ui_display/screens/event_markers.c - implemented as a new `roast_core/roast_events.c`/`.h` (event list + persistence via `roast_telemetry_service_record_event()`) plus a "Mark Event" button + full-screen 9-button overlay directly in `roast_dashboard.c` (not a separate `event_markers.c` screen file) - marking FC Start also auto-triggers the existing DTR-calculator's first-crack timestamp
- [X] T057 [P] Implement BatchRecord metadata form (coffee name, origin, weight, notes) in firmware/components/ui_display/screens/batch_metadata.c - implemented as a `batch_record_t` (storage/session_store.h, embedded in `session_meta_t`) filled in via a "Batch Info" button + overlay directly in `roast_dashboard.c` (not a separate `batch_metadata.c` file) while idle, applied to the session's metadata at roast start; displayed back in Roast History's session detail view (`session_review.c`) whenever any field was filled in
- [X] T058 Security review pass: confirm no-auth/trusted-network assumptions are documented in README, validate firmware upload checksum verification - added a "Security Considerations" section to `firmware/README.md` documenting the FR-021 no-auth/trusted-LAN assumption across the web dashboard, WiFi setup AP, Artisan Modbus bridge, and OTA upload endpoint, plus the lack of firmware image signature verification (Secure Boot not enabled); confirmed `esp_ota_end()` (`roaster_hal/ota_manager.c`) already validates image integrity (magic bytes/header/checksum) before switching the boot partition - no code change was needed for that part, just documenting it
- [X] T059 [P] Performance tuning: ensure telemetry/chart updates sustain 2-5 Hz without UI stutter on JC4827W543 - `roast_telemetry_service.c` already sampled at 500ms (2Hz); the on-device dashboard's own `lv_timer` already refreshed at 500ms (2Hz); the one gap found was the WEB dashboard's WebSocket broadcast timer (`dashboard_routes.c`), previously 1000ms (1Hz, below the 2-5Hz target) - bumped to 500ms (2Hz) so web clients now see updates exactly as often as the physical display. No real-hardware profiling was performed (not possible in this environment) - this is a code-review-based cadence adjustment; UI stutter itself was not measured on device
- [X] T060 Run quickstart.md validation end-to-end (all 9 scenarios in specs/001-pop-roaster-control/quickstart.md) - performed as a static "desk check" only (see `firmware/docs/quickstart-desk-check.md`): every scenario/step cross-referenced against the actual implementing code path by reading the source, NOT executed on a powered roaster (requires real heating element/sensor/fan hardware this environment doesn't have). 5 honest gaps were found and documented (no on-device Manual-mode-switch trigger, no `.alog` export, partial i18n coverage, unverified DTR/RoR numerical correctness, unverified Artisan event-register exposure) - none safety-critical, all require real hardware/Artisan to close out. The operator should still run the actual 8 scenarios on real hardware before considering this fully validated
- [X] T061 [P] Documentation: update README with hardware wiring (SSR 40A, PWM 15A, MAX6675) and setup instructions - created `firmware/README.md` (none existed before) covering build/flash instructions, the JST1.25 expansion connector pinout + default GPIO assignments (from `board_config/Kconfig`) for MAX6675/SSR/fan, a wiring diagram, a summary of the software safety interlocks, the Security Considerations section (T058), i18n status, and a link to the existing Artisan integration doc

---

## Dependencies & Execution Order

### Phase Dependencies

- **Setup (Phase 1)**: No dependencies - can start immediately
- **Foundational (Phase 2)**: Depends on Setup completion - BLOCKS all user stories
- **User Story 1 (Phase 3)**: Depends on Foundational completion - no dependency on other stories
- **User Story 2 (Phase 4)**: Depends on Foundational completion - independent of US1, but profile-mode control loop (T034) shares command dispatcher patterns from US1
- **User Story 3 (Phase 5)**: Depends on Foundational completion and on Mode Manager needing US2's profile curve follower (T034) to distinguish Profile vs Manual/Artisan
- **User Story 4 (Phase 6)**: Depends on Foundational completion - independent of US1/US2/US3
- **Polish (Phase 7)**: Depends on all desired user stories being complete

### User Story Dependencies

- **User Story 1 (P1)**: Can start after Foundational (Phase 2) - No dependencies on other stories
- **User Story 2 (P1)**: Can start after Foundational (Phase 2) - Independently testable; shares command dispatcher from US1 conceptually but has its own control loop
- **User Story 3 (P2)**: Can start after Foundational (Phase 2) - Integrates with US1 (command dispatcher, Emergency Stop, alarm ack) and US2 (profile curve follower) for Mode Manager and web/display parity, but web dashboard/telemetry itself is independently testable
- **User Story 4 (P3)**: Can start after Foundational (Phase 2) - Fully independent of US1/US2/US3

### Parallel Opportunities

- All Setup tasks marked [P] (T003-T005) can run in parallel
- Foundational tasks marked [P] (T007-T010, T013-T014, T017-T018) can run in parallel within Phase 2; T016 (GT911 touch integration) can run in parallel with the other foundational tasks
- Once Foundational completes, US1, US2, and US4 can be worked on in parallel by different developers; US3 benefits from US1/US2 being further along but can start in parallel with careful stubbing
- Within US1: T023 (Emergency Stop widget) can run in parallel with T021/T024-T029; T020 (pause/resume) and T022 (session review screen) can be developed in parallel with each other once T019/T021 are ready
- Within US2: T030 parallel with foundational work; T039-T040 (profile export/import) parallel with each other
- Within US3: T041 and T043 can run in parallel; T044 and T045 (web Emergency Stop / alarm ack) can run in parallel with each other once T043 is ready; T048 parallel with T041-T047
- Within US4: T050, T051, T054 can run in parallel with each other

---

## Parallel Example: User Story 1

```bash
# After T019 (command dispatcher) is done, these can run in parallel:
Task: "Implement Emergency Stop widget in firmware/components/ui_display/widgets/emergency_stop_button.c"
Task: "Implement critical alarm banner in firmware/components/ui_display/screens/alarm_banner.c"
Task: "Implement indirect fan-failure detection in firmware/components/safety/fan_failure_detector.c"
Task: "Implement operator-initiated pause/resume in firmware/components/roast_core/session_state_machine.c"
```

## Parallel Example: User Story 2

```bash
Task: "Implement profile export (JSON) endpoint in firmware/components/web_api/routes/profiles_export.c"
Task: "Implement profile import (JSON upload) endpoint in firmware/components/web_api/routes/profiles_import.c"
```

## Parallel Example: User Story 3

```bash
# After T043 (web dashboard page) is done, these can run in parallel:
Task: "Implement Emergency Stop control on the web dashboard"
Task: "Implement critical alarm banner with manual acknowledgment on the web dashboard"
```

---

## Implementation Strategy

### MVP First (User Story 1 Only)

1. Complete Phase 1: Setup
2. Complete Phase 2: Foundational (CRITICAL - blocks all stories, includes Safety Manager and GT911 touch integration)
3. Complete Phase 3: User Story 1 (Manual/Artisan roast with full safety interlocks)
4. **STOP and VALIDATE**: Run Cenário 1 and Cenário 2 (partial) from quickstart.md
5. Deploy/demo if ready — this is a safe, usable torrador even without profiles yet

### Incremental Delivery

1. Complete Setup + Foundational → Foundation ready (drivers, safety manager, storage, touch/GT911 integrated)
2. Add User Story 1 → Test independently → Deploy/Demo (MVP: safe manual roasting)
3. Add User Story 2 → Test independently → Deploy/Demo (repeatable profiles)
4. Add User Story 3 → Test independently → Deploy/Demo (web UI + Artisan, with web/display safety parity)
5. Add User Story 4 → Test independently → Deploy/Demo (maintenance/OTA)
6. Polish phase → i18n, event markers, batch metadata, quickstart full validation

### Parallel Team Strategy

With multiple developers:

1. Team completes Setup + Foundational together (Safety Manager is the critical path — prioritize it)
2. Once Foundational is done:
   - Developer A: User Story 1 (display safety flow)
   - Developer B: User Story 2 (profiles)
   - Developer C: User Story 4 (peripheral tests/OTA) — fully independent
   - User Story 3 (web/Artisan) starts once US1's command dispatcher/Emergency Stop/alarm ack and US2's curve follower have stable interfaces
3. Stories complete and integrate independently

---

## Notes

- [P] tasks = different files, no dependencies
- [Story] label maps task to specific user story for traceability
- Safety Manager (T012) is the single most critical foundational task — all hard-fail rules (30% fan floor, 260°C/240°C cutoff, watchdog, emergency stop, alarm ack) route through it
- Touch controller is confirmed as GT911 (I2C) with pins already defined in `firmware/components/board_config/boards/board_jc4827w543.h` — T016 is a direct integration task, not a discovery task
- Web dashboard now has explicit parity tasks for Emergency Stop (T044) and alarm acknowledgment (T045), matching the display-side widgets (T023, T024) per FR-027/FR-012
- No dedicated test-first tasks were generated (not requested in spec); quickstart.md scenarios (T060) serve as the acceptance validation pass
- Commit after each task or logical group
- Stop at any checkpoint to validate story independently

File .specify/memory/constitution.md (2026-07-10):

# Pop Roaster Constitution

## Core Principles

### I. Safety-First, Non-Negotiable
Every command that can affect the heater or fan (from display, web, or Artisan) MUST pass through a single, centralized Safety Manager before being applied — no UI, network client, or external integration may bypass it. Hard-fail rules (minimum ventilation floor, absolute temperature cutoff, sensor-failure cutoff, indirect fan-failure detection, maximum roast duration watchdog, dedicated Emergency Stop) are always enforced regardless of operating mode. Critical alarms MUST require explicit manual acknowledgment before the roast can continue. Any relaxation of a safety rule requires an explicit, documented decision (via `/speckit.clarify`) and must be recorded as a residual risk if accepted, never silently assumed.

### II. Domain/Interface Separation
Business logic (roast state machine, safety rules, profile curve following, RoR/DTR calculation) MUST NOT depend on any specific display, web framework, or external protocol. All hardware-specific details (pins, display driver, touch controller) are isolated behind a `board_config` contract so new boards/displays can be added by implementing that contract, without modifying `roast_core/`, `safety/`, or business rules elsewhere.

### III. Configuration Over Hardcoding
Hardware wiring that can vary between physical builds (external peripheral GPIOs for sensors/actuators wired via expansion connectors) MUST be configurable (e.g., via Kconfig/menuconfig) rather than hardcoded, so the same firmware source supports rewiring without code changes. Fixed, board-soldered hardware (the display panel and its touch controller) is defined once per board profile and treated as immutable for that board.

### IV. Data Integrity and Continuity
User-created data (roast profiles, roast session history, calibration) MUST survive power loss, reboots, and — where explicitly decided — deletion of related records (e.g., a session keeps its own snapshot of the profile used, independent of the profile's later deletion). Firmware updates MUST use a safe scheme (A/B partitions) where failure never leaves the device in a non-functional state. Users MUST be able to export/import their own data (profiles, sessions) independent of the device.

### V. Spec-Driven Development
All functional ambiguity MUST be resolved through the `/speckit.clarify` workflow and recorded in `spec.md` before or during planning — decisions are not to be assumed silently by whoever implements them. The standard flow for this project is: `/speckit.specify` → `/speckit.clarify` → `/speckit.plan` → `/speckit.tasks` → `/speckit.analyze` → `/speckit.implement`. Significant scope changes discovered mid-flow (e.g., new hardware facts, new safety considerations) require re-running the affected steps rather than patching artifacts inconsistently.

## Security & Trust Boundaries

The v1 scope explicitly trusts the local network the device is connected to: there is no authentication for the web interface, control commands, or firmware upload. This is a deliberate, documented trade-off for a single-user, home/workshop-network context — not an oversight. Any future work that exposes the device beyond a trusted local network (e.g., remote/cloud access) MUST revisit this principle explicitly via `/speckit.clarify` before being implemented, since the current design assumes physical/network isolation as the only access control.

Known accepted residual risks (documented in `spec.md` Assumptions) MUST remain visible there and MUST NOT be quietly removed without an explicit decision to mitigate or formally re-accept them.

## Development Workflow

- Every feature starts with a specification (`spec.md`) covering user stories, functional requirements, success criteria, and edge cases before any implementation planning begins.
- `/speckit.analyze` MUST be run after `/speckit.tasks` and before `/speckit.implement` to catch coverage gaps, inconsistencies, and drift between spec/plan/tasks; CRITICAL findings block implementation, MEDIUM/LOW findings are remediated or explicitly accepted by the user.
- Hardware facts (pinouts, chip models, module variants) MUST be grounded in verifiable sources (vendor documentation, component registries, physically confirmed pin tests) before being written into `research.md`/`plan.md`/board configuration files — assumptions must be clearly labeled as such until confirmed.
- Tests are optional per feature and only added when explicitly requested; when omitted, the `quickstart.md` scenarios serve as the acceptance validation pass before considering a feature done.

## Governance

This constitution supersedes ad-hoc practices for this project. Amendments require an explicit update to this file (via `/speckit.constitution` or direct edit) with a version bump and a note of what changed and why. All specs, plans, and tasks for this project should be checked against these principles during `/speckit.analyze`; any conflict is a CRITICAL finding that must be resolved by adjusting the spec/plan/tasks — not by silently ignoring the principle.

**Version**: 1.0.0 | **Ratified**: 2026-07-06 | **Last Amended**: 2026-07-06

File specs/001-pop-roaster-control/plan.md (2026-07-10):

# Implementation Plan: Pop Roaster Control Platform

**Branch**: `[001-pop-roaster-control]` | **Date**: 2026-07-06 | **Spec**: `specs/001-pop-roaster-control/spec.md`

**Input**: Feature specification from `specs/001-pop-roaster-control/spec.md`

## Summary

Construir uma plataforma embarcada para controle seguro de torra em pipoqueira elétrica (1200W), com interface local em display ESP32 (inicialmente JC4827W543), web UI em tempo real e compatibilidade bidirecional com Artisan (gated por modo). A abordagem técnica separa domínio de torra/safety das camadas de UI e integração para viabilizar expansão futura de displays, idiomas e modos de operação sem reescrever regras críticas. Após 12 sessões de clarificação (41 requisitos funcionais), o escopo agora inclui: dois modos de torra (Perfil e Manual/Artisan, com transição unidirecional), múltiplas camadas de segurança (piso fixo de ventilação, corte absoluto de temperatura, watchdog de duração, detecção indireta de falha de ventilação via RoR, parada de emergência dedicada, reconhecimento manual de alarmes), calibração de sensor, OTA com esquema A/B seguro, exportação/importação de dados (sessões e perfis), curva de RoR e DTR% em tempo real, marcos de torra completos (charge → dry end → first/second crack → drop → cooling) e i18n (EN/PT/ES, EN padrão).

## Technical Context

**Language/Version**: C/C++ (ESP-IDF estável compatível com ESP32-S3)

**Primary Dependencies**:
- ESP-IDF (FreeRTOS, NVS, OTA com esquema de partição A/B)
- `board_config` (componente próprio, `firmware/components/board_config/`) — abstração de hardware por board com Kconfig para pinos de periféricos externos
- `esp_lcd_nv3041` (componente do IDF Component Registry, `eric-c-e/esp_lcd_nv3041`) para o driver do painel NV3041A via `esp_lcd_panel_io_spi`
- `esp_lvgl_port` (integração oficial Espressif entre `esp_lcd` e LVGL) + LVGL (UI local, gráfico de curva BT+RoR, i18n de strings)
- `esp_lcd_touch_gt911` (família `esp_lcd_touch`) para o touch capacitivo GT911 confirmado via I2C
- Driver MAX6675 (aquisição de temperatura, com offset de calibração aplicado em software)
- Stack HTTP/WebSocket do ESP-IDF (web UI, telemetria em tempo real, upload de firmware/perfis)
- Adapter de protocolo Artisan (serial USB e/ou bridge TCP local, bidirecional apenas em Modo Manual/Artisan)

**Storage**:
- NVS para perfis, calibração, configuração de rede e idioma
- File system embarcado (LittleFS/SPIFFS) para histórico de sessões (retenção circular, padrão 30 sessões) e snapshots de perfil por sessão

**Testing**:
- Unit tests para regras de domínio (state machine de fases/modos, safety manager, cálculo de RoR/DTR)
- Integration/HIL para periféricos (sensor, SSR, PWM, detecção indireta de falha de ventilação)
- Contract tests para API web, exportação/importação (CSV/.alog/JSON) e adapter de compatibilidade Artisan (leitura e escrita)

**Target Platform**: JC4827W543 (Guition) — ESP32-S3-WROOM-1-N4R8 (8MB PSRAM, 4MB Flash), display 480x272 com driver NV3041A via QSPI, touch capacitivo GT911 via I2C (SCL:4, SDA:8, RST:38, INT:3)

**Project Type**: Sistema embarcado com UI local + web app embarcada + adapter de integração externa bidirecional

**Performance Goals**:
- Atualização de telemetria e gráfico (BT + RoR) em 2-5 Hz sem travamentos perceptíveis
- Aplicação de comandos críticos (incluindo Parada de Emergência) com latência local percebida abaixo de 200 ms

**Constraints**:
- Aquecimento nunca pode operar com ventilação abaixo do piso fixo de 30%
- Falha de leitura do sensor ou detecção indireta de falha de ventilação (via RoR) deve forçar aquecimento OFF
- Corte absoluto de segurança a 260°C (aviso prévio a 240°C), independente do perfil ou modo ativo
- Watchdog de duração máxima de torra (padrão 25 min) força resfriamento automático
- Controle local deve continuar funcional mesmo sem rede/web
- Artisan só pode enviar comandos de controle quando a sessão estiver em Modo Manual/Artisan; em Modo Perfil é somente leitura
- Troca de Modo Perfil → Manual/Artisan é permitida mid-roast, mas irreversível na mesma sessão
- Alarmes críticos exigem reconhecimento manual do operador (sem buzzer; sinalização exclusivamente visual)
- Memória embarcada limitada, exigindo retenção rotativa de histórico e snapshot de perfil por sessão

**Scale/Scope**:
- 1 equipamento por instância
- 1 operador por sessão de torra
- Múltiplos perfis (com export/import JSON) e histórico local com retenção configurável (padrão 30 sessões)
- Interface em 3 idiomas (EN padrão, PT, ES)

## Constitution Check

*GATE: Must pass before Phase 0 research. Re-check after Phase 1 design.*

### Pre-Phase 0

- Constitution file (`.specify/memory/constitution.md`) at the time of initial planning contained only unfilled placeholders (no enforceable principles).
- Gate status at that time: **PASS PROVISÓRIO** (no formal rules to block planning).
- Mitigation applied in the plan: safety-by-design, 3-level testability, and domain/UI separation.

### Post-Phase 1 Re-check (updated after constitution was ratified)

- Constitution ratified 2026-07-06 (v1.0.0) with 5 core principles: Safety-First, Domain/Interface Separation, Configuration Over Hardcoding, Data Integrity and Continuity, Spec-Driven Development — see `.specify/memory/constitution.md`.
- Re-checked this plan and `tasks.md` against all 5 principles:
  - **I. Safety-First**: PASS — single `safety_manager.c` (T012) validates every command from display/web/Artisan; alarms require manual ack (T024/T045); Emergency Stop mirrored on display and web (T023/T044).
  - **II. Domain/Interface Separation**: PASS — `board_config` component isolates hardware; `roast_core`/`safety` never reference display/web/Artisan specifics.
  - **III. Configuration Over Hardcoding**: PASS — external peripheral GPIOs configurable via Kconfig (`board_config/Kconfig`); fixed board hardware (display/touch) defined once per board header.
  - **IV. Data Integrity and Continuity**: PASS — profile snapshot per session (T037), A/B safe OTA (T052/T053), profile/session export-import (T039/T040/T048).
  - **V. Spec-Driven Development**: PASS — spec.md went through 9 `/speckit.clarify` sessions before this plan; `/speckit.analyze` was run and its findings (C1-C7) were remediated in `tasks.md`.
- Re-check status: **PASS** (no violations against the ratified constitution).

### Constitution Amendment Trigger

- If the trust boundary changes (e.g., exposing the device beyond a local trusted network), the Security & Trust Boundaries section of the constitution requires re-running `/speckit.clarify` before implementation — this is a standing amendment trigger, not yet activated in this feature's v1 scope.

## Phase 0 Research Output

Pesquisa consolidada em `specs/001-pop-roaster-control/research.md` com decisões para:
- stack de firmware e arquitetura por camadas
- modelagem de safety/intertravamento (piso fixo de ventilação, corte absoluto de temperatura, watchdog de duração, detecção indireta de falha de ventilação via RoR, parada de emergência, reconhecimento manual de alarmes)
- compatibilidade com Artisan bidirecional gated por Modo Perfil/Manual-Artisan
- estratégia de web UI em tempo real
- persistência, retenção e snapshot de perfil por sessão
- OTA com esquema A/B e rollback seguro
- calibração de sensor, exportação/importação de dados (sessões e perfis)
- curva de RoR, DTR% e marcos de torra completos
- suporte a i18n (EN padrão, PT, ES)

## Phase 1 Design Output

- Modelo de dados: `specs/001-pop-roaster-control/data-model.md`
- Contratos:
  - `specs/001-pop-roaster-control/contracts/web-api.yaml`
  - `specs/001-pop-roaster-control/contracts/artisan-compatibility.md`
- Guia de validação: `specs/001-pop-roaster-control/quickstart.md`

### Agent Context Update

- Tentativa de execução do script de atualização: `.specify/scripts/powershell/update-agent-context.ps1`
- Resultado: **indisponivel neste template** (`MISSING:update-agent-context.ps1`)
- Impacto: nenhum bloqueio para planejamento; etapa de tasks/implement pode seguir normalmente.

## Project Structure

### Documentation (this feature)

```text
specs/001-pop-roaster-control/
├── plan.md
├── research.md
├── data-model.md
├── quickstart.md
├── contracts/
│   ├── web-api.yaml
│   └── artisan-compatibility.md
└── tasks.md
```

### Source Code (repository root)

```text
firmware/
├── main/
├── components/
│   ├── board_config/     # Kconfig + headers de board (display/touch fixos, GPIOs de perifericos configuraveis)
│   ├── roast_core/       # state machine de fases, modos (Perfil/Manual-Artisan), RoR/DTR
│   ├── safety/           # safety manager: piso de ventilacao, corte absoluto, watchdog, ack de alarmes
│   ├── hal/              # drivers MAX6675 (com calibracao), SSR, PWM
│   ├── storage/          # NVS (perfis, config, idioma), LittleFS (sessoes, snapshots)
│   ├── ui_display/       # LVGL, i18n de strings, telas (perfil, manual/artisan, testes, OTA)
│   ├── web_api/          # HTTP/WebSocket, export/import (CSV/.alog/JSON), OTA upload
│   └── artisan_adapter/  # serial/TCP bridge, leitura sempre + escrita gated por modo
└── test/

webui/
└── src/

tests/
├── unit/
├── integration/
├── contract/
└── hil/
```

**Structure Decision**: Arquitetura de firmware modular com separacao entre dominio e adaptadores de interface. O mesmo core de torra/safety atende display local, web UI e integração Artisan.

## Complexity Tracking

Nenhuma excecao formal registrada nesta fase.

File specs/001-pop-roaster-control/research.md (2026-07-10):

# Research: Pop Roaster Control Platform

## Decision 1: Firmware stack e arquitetura de runtime

- Decision: Usar ESP-IDF (C/C++) como base de firmware com arquitetura em camadas: HAL de hardware, Core de torra (estado, modos e segurança), e adapters de interface (display, web, Artisan).
- Rationale: ESP-IDF oferece controle determinístico de tarefas, watchdog, NVS, OTA A/B e ecossistema robusto para produto embarcado. A separação por camadas desacopla regras de torra da UI e facilita suporte a múltiplos displays, idiomas e modos de operação.
- Alternatives considered:
  - Arduino framework puro: menor curva inicial, mas menos previsibilidade para concorrência e manutenção em crescimento.
  - Micropython: rápido para protótipo, porém com limitações de desempenho/integração para UI gráfica e telemetria contínua.

## Decision 2: Hardware real do JC4827W543 e stack de display/touch

- Decision: Confirmado via documentação oficial do fabricante ([github.com/lsdlsd88/JC4827W543](https://github.com/lsdlsd88/JC4827W543)) e via documentação comunitária detalhada ([github.com/profi-max/JC4827W543_4.3inch_ESP32S3_board](https://github.com/profi-max/JC4827W543_4.3inch_ESP32S3_board)) que o JC4827W543 usa MCU **ESP32-S3-WROOM-1-N4R8** (520KB RAM, 8MB PSRAM OSPI, 4MB Flash QSPI), display **480x272** RGB565 com driver de painel **NV3041A** via QSPI (CS:45, SCK:47, D0:21, D1:48, D2:40, D3:39, backlight:1), e touch capacitivo **GT911 via I2C** (SCL:4, SDA:8, RST:38, INT:3, endereço 0x5D). A placa expõe até 10 GPIOs livres via conectores JST1.25 para periféricos externos (SSR, PWM, MAX6675). Para o firmware ESP-IDF nativo, usar o componente do IDF Component Registry `eric-c-e/esp_lcd_nv3041` (via `idf.py add-dependency "eric-c-e/esp_lcd_nv3041^0.1.1"`), construído sobre `esp_lcd_panel_io_spi`, integrado ao LVGL via `esp_lvgl_port` (componente oficial Espressif); o touch GT911 é integrado via componente `esp_lcd_touch_gt911` da família `esp_lcd_touch`. Um componente `board_config` foi criado (`firmware/components/board_config/`) definindo um contrato de macros que qualquer board futuro deve implementar (display/touch fixos por header específico em `boards/`), enquanto os pinos dos periféricos externos (MAX6675, SSR, PWM da ventoinha) são configuráveis via Kconfig/`idf.py menuconfig`, independente do board selecionado.
- Rationale: Os exemplos oficiais do fabricante são baseados em Arduino_GFX + LVGL sobre Arduino core, mas existe um driver ESP-IDF nativo equivalente para o NV3041A no Component Registry, permitindo manter a arquitetura ESP-IDF pura (Decision 1) sem reescrever um driver de painel do zero. Separar pinos fixos do board (display/touch) de pinos configuráveis do usuário (periféricos via JST1.25) atende ao requisito de suportar futuros displays (FR-017) sem reescrever regras de negócio, e permite ao usuário testar diferentes GPIOs para os periféricos sem editar código.
- Pinagem física confirmada dos conectores JST1.25 (4 pinos cada, na ordem de conexão): P1 = GND, RXD, TXD, +5V (UART/energia); P2 = IO46, IO9, IO14, IO5; P3 = IO6, IO7, IO15, IO16; P4 = GND, 3.3V, IO17, IO18. IO46 é **input-only** no ESP32-S3 (não pode acionar saídas), portanto foi atribuído por padrão ao SO/MISO do MAX6675 (sinal de leitura); SCK/CS do MAX6675, SSR e PWM da ventoinha usam pinos de saída (IO5, IO6, IO7, IO15 por padrão), com IO9/IO14/IO16/IO17/IO18 disponíveis como reserva para expansão futura (ex.: feedback de RPM da ventoinha).
- Alternatives considered:
  - Usar Arduino core + Arduino_GFX + LVGL (stack oficial do fabricante): bring-up mais rápido (exemplos prontos), mas introduziria uma segunda camada de framework (Arduino sobre IDF) com overhead e menos controle fino sobre tarefas/memória — rejeitado.
  - Escrever driver NV3041A/QSPI customizado do zero em ESP-IDF puro: mais controle, porém trabalho redundante dado que já existe um componente publicado e mantido — rejeitado em favor de reaproveitar o componente `esp_lcd_nv3041`.
  - Hardcode dos pinos de periféricos externos no código-fonte: mais simples, porém exigiria recompilar a cada teste de fiação diferente — rejeitado em favor de Kconfig configurável via menuconfig.

## Decision 3: Interface gráfica local para JC4827W543, i18n e escalabilidade de telas

- Decision: Usar LVGL com camada de abstração de layout (tokens de dimensão, grid responsivo, componentes reutilizáveis) e um catálogo de strings traduzíveis (EN padrão, PT, ES) carregado pela UI, independente da resolução do display.
- Rationale: LVGL é padrão de mercado em ESP32 com boa performance; a separação de strings em catálogo permite trocar idioma em runtime (FR-038) e escalar para novos displays sem duplicar lógica de domínio.
- Alternatives considered:
  - UI proprietária fixa por resolução/idioma: entrega inicial rápida, mas alto retrabalho em novos displays e sem suporte real a múltiplos idiomas.
  - Strings hardcoded no código: simples, mas exige recompilação por idioma — descartado por não atender troca em runtime (FR-038).

## Decision 4: Modos de operação e Safety Manager

- Decision: Modelar dois modos de sessão mutuamente exclusivos: **Modo Perfil** (segue curva de `RoastProfile`, Artisan somente leitura) e **Modo Manual/Artisan** (sem curva própria; aceita comandos do operador via display/web e do Artisan, todos sob o mesmo esquema last-write-wins). Transição permitida apenas Perfil → Manual/Artisan, mediante confirmação explícita e irreversível na sessão (FR-039, FR-040). Um Safety Manager centralizado intercepta todo comando de qualquer fonte (display, web, Artisan) antes da aplicação, independente do modo.
- Rationale: Atende ao requisito de segurança do usuário (Artisan só controla quando o operador sai conscientemente do Modo Perfil) sem duplicar lógica de validação por canal de entrada.
- Alternatives considered:
  - Bidirecional sempre-ativo (sem gate de modo): mais simples, porém permite que um software externo no PC acione atuadores mesmo durante execução automática de perfil — rejeitado por risco de segurança.
  - Três modos separados (Manual, Perfil, Artisan): mais granular, mas o usuário preferiu unificar Manual e Artisan em um único modo simplificado.

## Decision 5: Regras de segurança hard-fail (Safety Rules)

- Decision: Implementar as seguintes regras não negociáveis no Safety Manager, aplicadas independentemente de modo ou fonte de comando:
  1. Aquecimento requer ventilação ≥ 30% (piso fixo em firmware, não configurável) sempre que ativo.
  2. Corte absoluto de temperatura em 260°C (aviso prévio em 240°C), independente do perfil.
  3. Falha de leitura do sensor força aquecimento OFF e alarme crítico.
  4. Detecção indireta de falha de ventilação via padrão anômalo de RoR força aquecimento OFF e alarme crítico.
  5. Watchdog de duração máxima de torra (padrão 25 min, configurável) força transição automática para resfriamento.
  6. Parada de Emergência dedicada, sempre acessível, corta aquecimento imediatamente.
  7. Alarmes críticos (itens 2-4 e 6) exigem reconhecimento manual do operador antes de a torra continuar.
- Rationale: Requisitos de segurança críticos definidos ao longo de 6+ sessões de clarificação para proteger o equipamento (resistência de pipoqueira) e compensar a ausência de sensores redundantes (sem tacômetro de ventoinha, sem proteção física independente do SSR).
- Alternatives considered:
  - Proteção física redundante (fusível térmico/termostato) contra falha do SSR: recomendada como boa prática, mas explicitamente recusada pelo usuário para a v1 (risco residual documentado no spec).
  - Feedback de RPM na ventoinha: mais robusto, mas descartado pelo usuário em favor de detecção indireta via curva de temperatura (mais simples, sem hardware adicional).

## Decision 6: Aquisição de temperatura, calibração e papel do sensor (BT)

- Decision: Leitura MAX6675 tratada como BT (Bean Temperature) real, pois o sensor fica em contato direto com os grãos. Pipeline de validação (faixa plausível, valor travado, timeout) mais um offset de calibração configurável pelo operador (validado contra referência conhecida, ex. água fervendo), aplicado a todas as leituras subsequentes.
- Rationale: Sensor único fisicamente posicionado nos grãos torna a nomenclatura BT correta e compatível com o Artisan; calibração compensa erro sistemático comum em termopares baratos, essencial para um usuário leigo confiar na curva.
- Alternatives considered:
  - Tratar como ET (Environment Temperature): descartado, pois não reflete a posição real do sensor.
  - Sem calibração (leitura bruta sempre): descartado por gerar curvas sistematicamente deslocadas sem que o operador perceba.

## Decision 7: Persistência local, snapshot de perfil e backup

- Decision: Persistir perfis, calibração, configuração de rede/idioma em NVS; histórico de sessões em LittleFS/SPIFFS com retenção circular (padrão 30 sessões, configurável). Cada sessão armazena um snapshot próprio da curva/parâmetros do perfil usado no momento da execução (para não depender do perfil original após exclusão). Perfis exportáveis/importáveis em JSON via web; sessões exportáveis em CSV e/ou `.alog` (Artisan).
- Rationale: NVS é ótimo para dados pequenos/chave-valor; snapshot por sessão garante integridade histórica mesmo com exclusão de perfis; export/import cobre backup e continuidade de dados em caso de troca/falha de dispositivo.
- Alternatives considered:
  - Sessão apenas referenciando `profileId`: mais simples, mas quebra o histórico se o perfil for excluído — rejeitado.
  - Banco externo obrigatório: aumentaria complexidade e dependência de rede — rejeitado.

## Decision 8: Interface Web unificada, tempo real e i18n

- Decision: Servir dashboard web no próprio ESP32 com WebSocket para telemetria/controle em tempo real (BT, RoR, DTR%, fase, modo) e endpoints HTTP para configuração, perfis (incl. export/import), sessões (incl. export), OTA upload e idioma. UI web compartilha o mesmo catálogo de strings i18n do display.
- Rationale: Mantém operação local sem internet, permite acesso por celular/computador na mesma rede, e evita duplicar traduções entre display e web.
- Alternatives considered:
  - Polling HTTP puro: pior latência e experiência para gráfico de curva/RoR em tempo real.
  - App mobile nativo no v1: alto custo para versão inicial.

## Decision 9: Compatibilidade com Artisan (bidirecional gated por modo)

- Decision: Adapter de protocolo compatível com o Artisan via serial USB e/ou bridge TCP local. Em **Modo Manual/Artisan**, o adapter aceita comandos de controle do Artisan (aplicados pelo mesmo Safety Manager que valida comandos locais/web). Em **Modo Perfil**, o adapter opera estritamente como somente leitura (telemetria e eventos), ignorando qualquer comando recebido.
- Rationale: Reflete o uso real do Artisan (operador humano ajustando sliders/botões no software) sem comprometer a automação de perfil; maximiza interoperabilidade com a comunidade de torra mantendo a segurança local intacta.
- Alternatives considered:
  - Somente leitura sempre: mais simples e seguro, mas não atende ao caso de uso de controle remoto que o usuário quer explicitamente.
  - Bidirecional irrestrito em qualquer modo: rejeitado por risco de conflito com a automação de perfil.

## Decision 10: Estratégia de OTA (esquema A/B seguro)

- Decision: OTA por upload web com validação de imagem, instalação em partição secundária (esquema A/B); o boot só chaveia para a nova partição após instalação completa e validada com sucesso. Falha em qualquer etapa mantém o sistema na partição atual, sem risco operacional.
- Rationale: Elimina risco de "brick" do dispositivo por atualização malsucedida — crítico para um usuário sem experiência em recuperação manual de firmware.
- Alternatives considered:
  - Atualização apenas por cabo/IDE: barreira alta para manutenção.
  - Partição única sem rollback: risco operacional elevado, rejeitado explicitamente pelo usuário.

## Decision 11: Telemetria avançada (RoR, DTR%, marcos de torra)

- Decision: Calcular e exibir curva de RoR junto à curva de BT (display e web); calcular e exibir DTR% em tempo real a partir do evento de first crack; suportar marcos completos de torra (charge, turning point, dry end, first crack start/end, second crack start/end, drop, cool start, manual note, alarm).
- Rationale: Replica as características centrais de interfaces profissionais de referência (Kaleido, Stratto Lab, Artisan) citadas pelo usuário, fornecendo dados-chave para decisão de drop mesmo para operador iniciante.
- Alternatives considered:
  - Apenas curva de BT, sem RoR/DTR: mais simples, mas descartado por reduzir o valor educativo/profissional da interface.

## Decision 12: Testabilidade

- Decision: Estratégia de testes em 3 níveis: unitários do Core de torra/safety (incluindo state machine de modos e cálculo de RoR/DTR), integração de drivers em hardware-in-loop (sensor, SSR, PWM, detecção indireta de falha), e testes de contrato para web, export/import e adapter Artisan (leitura e escrita).
- Rationale: Cobertura equilibrada para regras críticas de segurança e interfaces externas bidirecionais.
- Alternatives considered:
  - Só testes manuais: insuficiente para regressão de segurança em um sistema com múltiplos modos e fontes de comando.

## Decision 13: Itens adicionais de segurança e usabilidade para iniciantes

- Decision: Incluir desde o v1: confirmações obrigatórias (teste de aquecimento, troca de modo, upload de firmware), calibração guiada de sensor, sinalização visual de pré-aquecimento pronto (sem buzzer — hardware não possui), watchdog de duração máxima, e i18n (EN padrão) para acessibilidade a diferentes usuários.
- Rationale: Acelera aprendizado, reduz risco de erro operacional e amplia o alcance do projeto para além do público de língua portuguesa.
- Alternatives considered:
  - Deixar i18n e calibração para versões futuras: reduziria valor prático e seria uma regressão em relação às decisões já tomadas com o usuário.

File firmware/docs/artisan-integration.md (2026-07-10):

# Integração com o Artisan (Modbus TCP)

Este documento explica como configurar o [Artisan](https://artisan-scope.org/) para ler a temperatura/RoR e (opcionalmente) controlar o Fan/Heater do PopRoaster pela rede, sem cabo serial e sem nenhum programa extra no PC.

O PopRoaster expõe um **servidor Modbus TCP** na porta **502** (implementado em `firmware/components/artisan_adapter/artisan_bridge.c`). O Artisan tem suporte nativo a Modbus (confirmado no código-fonte dele, `artisanlib/modbusport.py`), então basta apontar o Artisan para o IP do torrador.

> **Nota**: os passos exatos (nomes de botões/abas) foram confirmados lendo o código-fonte e os arquivos de ajuda do Artisan, mas não foram testados clicando na interface real do Artisan neste ambiente. Se algum nome de campo estiver ligeiramente diferente na sua versão, o conceito (Modbus, TCP, host/porta, registradores) é o mesmo.

## 1. Pré-requisitos

- O torrador precisa estar conectado à sua rede WiFi (não no modo "PopRoaster-Setup").
- Descubra o IP do torrador: tela **Config** no display (mostra `http://<ip>/wifi` e `http://<ip>/ota`) ou a página `/wifi` / `/diagnostics` na web.
- Anote esse IP - vamos usar como "Host" no Artisan.

## 2. Configurar o dispositivo Modbus no Artisan

1. Menu **Config → Device...** (ou **Port...**/**Comm...**, dependendo da versão - é a tela onde se escolhe o "Meter"/dispositivo de leitura de temperatura, **não** a lista de marcas/modelos de torrador ("Machine"), que não tem opção Modbus).
2. Em **Meter**, selecione **Modbus**.
3. Abra as configurações de porta (botão **Port...** ou **Comm...** dentro dessa mesma tela) e configure:
   - **Comm Type / Mode**: `TCP`
   - **Host**: o IP do torrador (ex.: `192.168.5.4`)
   - **Port**: `502`
   - **Byte/Word order**: não é usado (não usamos registradores float de 32 bits, veja a tabela abaixo) - pode deixar no padrão.

## 3. Mapear os canais (registradores)

O PopRoaster usa **registradores Holding (function code 3 para leitura, 6 para escrita)**, com valores inteiros escalados (sem float), para evitar qualquer ambiguidade de "word order". Configure os canais assim:

| Canal Artisan | Device ID (Slave) | Registrador | Function | Div | Signed |
|---|---|---|---|---|---|
| BT (Bean Temp) | 1 | 0 | 3 (Read Holding Registers) | 1/10 | não |
| Channel extra "Fan" | 1 | 1 | 3 | nenhum | não |
| Channel extra "Heater" | 1 | 2 | 3 | nenhum | não |
| Channel extra "RoR" (opcional - o Artisan já calcula RoR sozinho a partir do BT) | 1 | 3 | 3 | 1/10 | **sim** |

- **ET (Environment Temp)**: deixe o Device ID do ET como `0` (desliga esse canal) - o PopRoaster só tem um sensor (BT).
- **Div = 1/10**: o registrador guarda a temperatura multiplicada por 10 (ex.: `2350` = 235.0°C) - o Artisan divide de volta automaticamente.
- **Signed** no canal de RoR: o valor pode ficar negativo durante o resfriamento.

## 4. Controlar Fan/Heater pelo Artisan (opcional)

Isso só funciona quando o torrador está em **modo Manual/Artisan** (se estiver em modo Perfil, os comandos do Artisan são ignorados de propósito - trava de segurança do projeto).

1. Menu **Config → Events → Sliders...** (Event Custom Sliders).
2. Crie (ou reaproveite) um slider, marque para aparecer (**Event**), e configure:
   - **Action**: `Modbus Command`
   - **Command**:
     - Slider de Fan: `writeSingle(1,100,{})`
     - Slider de Heater: `writeSingle(1,101,{})`
   - **Min**: `0`, **Max**: `100`
3. Ao soltar o slider, o Artisan escreve o valor (0-100) no registrador correspondente via Modbus function 6, e o torrador aplica o comando (Fan/Heater) exatamente como se tivesse sido feito pelo display ou pela web.

Você também pode usar um **Event Button** com a mesma Action `Modbus Command` e um comando fixo, por exemplo `writeSingle(1,101,0)` para "desligar o heater".

## 5. Tabela de registradores (referência rápida)

| Registrador | Conteúdo | Leitura/Escrita | Observação |
|---|---|---|---|
| 0 | Bean Temp × 10 | Leitura | Div=1/10 no Artisan |
| 1 | Fan % (0-100) | Leitura | valor real aplicado no ventilador |
| 2 | Heater % (0-100) | Leitura | valor real aplicado na resistência |
| 3 | RoR × 10 (com sinal) | Leitura | Div=1/10, Signed |
| 100 | Set Fan % (0-100) | **Escrita** | só tem efeito em modo Manual/Artisan |
| 101 | Set Heater % (0-100) | **Escrita** | só tem efeito em modo Manual/Artisan |

## 6. Testando

1. No Artisan, clique em **ON** (ligar a leitura). O BT deve aparecer e acompanhar a leitura do display do torrador.
2. Se não conectar: confirme que o PC e o torrador estão na mesma rede, que o IP está correto, e que nenhum firewall do PC está bloqueando a porta 502 de saída.
3. Se os valores de temperatura aparecerem estranhos (ex.: 10x maior/menor): confira se o Div=1/10 foi realmente aplicado ao canal de BT.

## Referências

- Firmware: `firmware/components/artisan_adapter/artisan_bridge.h` (mapa de registradores documentado no código também).
- Protocolo confirmado em `artisanlib/modbusport.py` no repositório oficial do Artisan: <https://github.com/artisan-roaster-scope/artisan>.
- Comandos de slider/botão Modbus (`writeSingle`, `read`, etc.) documentados na ajuda embutida do Artisan (Config → Events → Sliders/Buttons → botão de ajuda).

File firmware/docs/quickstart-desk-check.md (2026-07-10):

# Quickstart Validation — Desk Check (T060)

**Status: static code-path cross-reference only — NOT executed on real
hardware.** This document maps each scenario in
[`specs/001-pop-roaster-control/quickstart.md`](../../specs/001-pop-roaster-control/quickstart.md)
to the firmware code paths that are expected to satisfy it, as a "desk
check" performed by reading the implementation. It does **not** substitute
for actually running the 8 scenarios on a powered roaster with a real
MAX6675/SSR/fan/display, which the operator still needs to do. Where a gap
or an honest caveat exists, it's called out explicitly rather than glossed
over.

## Cenário 1: Segurança básica de aquecimento

| Step | Expected | Code path |
|---|---|---|
| 3 (fan < 30%, heater blocked) | Blocked + alarm | `safety_manager_request_heater_pct()` in [`components/safety/safety_manager.c`](../components/safety/safety_manager.c) rejects heater>0 while `s_last_fan_pct < SAFETY_MIN_FAN_PCT_FOR_HEATER` (30) |
| 4 (fan ≥ 30%, heater accepted) | Accepted | Same function — passes once fan ≥ 30 |
| 5 (sensor failure) | Auto heater-off + critical alarm | `safety_manager_on_temperature_sample()` detects invalid reads, calls `ssr_heater_force_off()` + raises `SAFETY_ALARM_SENSOR_FAILURE` |
| 6 (manual ack required) | New heater command blocked until ack | `s_alarm_needs_ack` checked unconditionally in `safety_manager_request_heater_pct()`; cleared only via `command_dispatcher_acknowledge_alarm()` |
| 7 (E-Stop) | Immediate heater cut + session cancel | `command_dispatcher_emergency_stop()` calls `safety_manager_emergency_stop()` + `session_sm_cancel()` (forces COOLING immediately, distinct from a normal Cooling-segment completion) |

**Desk-check verdict:** all 5 expectations have a clear, direct code path.
No gaps identified by inspection.

## Cenário 2: Fluxo operacional completo

| Step | Expected | Code path |
|---|---|---|
| 2 (CHARGE confirmation) | CHARGE only after explicit operator action | `session_sm_confirm_charge()` (PREHEAT→ROASTING), triggered only by the dashboard's "Charge" button / `command_dispatcher_confirm_charge()` — never automatic |
| 3 (live BT/RoR curve) | Real-time updates | `roast_telemetry_service` samples every 500ms; `roast_dashboard.c`'s `refresh_timer_cb` (also 500ms) repaints chart+labels from the cached snapshot |
| 4 (FC mark → DTR%) | DTR appears once FC marked | `roast_events_mark(ROAST_EVENT_TYPE_FC_START)` calls `roast_telemetry_service_mark_first_crack()`; `dtr_calculator.h` computes DTR% only once that timestamp is set |
| 5 (manual override holds until next curve point) | Override then curve resumes | `profile_curve_follower.c`: compares actual vs. last-written fan/heater each tick; on mismatch sets `s_override_active` until `roast_profile_get_segment_index()` changes (next segment boundary) |
| 6 (Cooling — heater off, fan on) | Correct | `profile_curve_follower.c`'s COOLING branch never writes heater; fan follows either the profile's own cooling segment or a fallback 100% |
| 7 (duration watchdog, 25 min default) | Auto-cooling + critical alarm | `safety/duration_watchdog.c`, 1s timer, compares `session_sm_get_state()->elapsed_ms` against `SAFETY_DEFAULT_MAX_DURATION_MS`; on exceed calls `safety_manager_report_duration_exceeded()` + `session_sm_start_cooling()` |

**Desk-check verdict:** covered end-to-end. One nuance worth flagging to
the operator: DTR%/RoR math have not been validated against a real roast
curve for numerical correctness (arithmetic was unit-reasoned, not measured
against known-good values from an actual bean mass/heater combination) —
worth a sanity comparison against Artisan's own DTR/RoR numbers during the
first real test roast.

## Cenário 3: Perfis, persistência em NVS e backup

| Step | Expected | Code path |
|---|---|---|
| 1-2 (create/save) | Persisted | `profile_editor.c` + `profile_store_create()`/`update()` (NVS blob) |
| 3 (export JSON) | Correct JSON | `GET /api/presets/export?id=N` in [`presets_routes.c`](../components/web_api/presets_routes.c) |
| 4-5 (reboot, reload, start session) | Profile survives reboot | NVS persistence is inherently reboot-safe; `profile_store_init()` reads the same index/blob keys on every boot |
| 6 (delete original, history keeps its own snapshot) | History unaffected by deletion | `session_meta_t.profile` is a **full struct copy**, captured at roast start (`roast_telemetry_service_on_roast_started()`), independent of the live `profile_store` entry |
| 7 (re-import JSON) | Profile recreated | `POST /api/presets/import` in `presets_routes.c`, calls `profile_store_create()` |

**Desk-check verdict:** covered. Import/export round-trip (export then
re-import the exact same file) has not been executed end-to-end on device —
only each direction was build-verified independently.

## Cenário 4: Web UI paridade mínima

| Step | Expected | Code path |
|---|---|---|
| 1-2 (open web UI, view chart/state) | Consistent with display | `dashboard_routes.c`'s `/ws/telemetry` WebSocket broadcasts the same `roast_telemetry_service` snapshot the display reads, now at 500ms (2Hz, bumped from 1Hz this session for T059) |
| 3 (fan adjust via web) | Goes through safety validation | `POST /api/control` → `command_dispatcher_set_fan_pct(..., SAFETY_CMD_SOURCE_WEB)` — same `safety_manager` gate as any other source |
| (implicit) web disconnect doesn't affect local control | True by construction | Web clients only ever read the snapshot / dispatch through `command_dispatcher`; nothing in the control loop (`profile_curve_follower`, safety timers) depends on a live WS connection |

**Desk-check verdict:** covered.

## Cenário 5: Compatibilidade com Artisan

| Step | Expected | Code path |
|---|---|---|
| 2 (Artisan command ignored in Profile mode) | Read-only gate | `command_dispatcher.c` checks `session_sm_get_state()->control_mode == ROAST_MODE_PROFILE` and rejects `SAFETY_CMD_SOURCE_ARTISAN` writes |
| 3 (irreversible mode-switch warning) | Warning shown | `session_sm_switch_to_manual_artisan()` gate + confirmation UI — **only reachable from the web dashboard's "Switch to Manual" button today; no on-device (display) trigger exists yet** (documented gap, carried over from an earlier session, not newly introduced) |
| 4 (Artisan command accepted post-switch) | Accepted + safety-validated | Same `command_dispatcher` path, now allowed once `control_mode == ROAST_MODE_MANUAL_ARTISAN` |
| 5 (manual event mark visible externally) | Visible over Modbus | `roast_events_mark()` persists via `roast_telemetry_service_record_event()`; `artisan_bridge.c` (esp-modbus v2.1 TCP slave) exposes live telemetry registers Artisan polls — event-specific register exposure was not re-verified this session (Artisan's own timeline reconstruction relies on register polling cadence, not a push notification) |

**Desk-check verdict:** mostly covered; the two caveats above (no on-device
Manual-mode-switch trigger, and event-register exposure not freshly
re-verified) are genuine gaps/unknowns, not resolved by this desk check.

## Cenário 5b: Exportação de sessões concluídas

| Step | Expected | Code path |
|---|---|---|
| 2 (CSV export) | Works | `GET /api/sessions/export?...&format=csv` in `history_routes.c` |
| 3 (.alog export) | Works | **Not implemented** — `history_routes.c`'s comment explicitly defers `.alog` export; only CSV exists |

**Desk-check verdict:** partial gap, already known/documented in
`tasks.md` — `.alog` (Artisan native log format) export was never built.

## Cenário 6: Testes de periféricos e calibração

| Step | Expected | Code path |
|---|---|---|
| 1-4 (peripheral test screen, sensor/fan/heater tests) | Independent status per peripheral, heater test gated by confirmation | `ui_display/screens/peripheral_test.c` |
| 5 (calibration offset) | Applied to all subsequent reads | `ui_display/screens/sensor_calibration.c` + `max6675.c` applying stored NVS offset |

**Desk-check verdict:** covered (implementation reviewed to exist and wire
correctly; exact UX/confirmation wording not re-verified this session).

## Cenário 7: Atualização de firmware (OTA)

| Step | Expected | Code path |
|---|---|---|
| 2 (invalid upload rejected) | Clear rejection | `ota_manager_end_and_activate()`'s `esp_ota_end()` call validates magic/header/checksum before switching boot pointer |
| 3-5 (valid upload installs, switches boot, confirms version) | Standard ESP-IDF OTA A/B flow | `ota_manager.c` + `partitions.csv`'s `ota_0`/`ota_1` scheme |
| 6 (power loss mid-install) | Falls back to current valid partition | Inherent ESP-IDF OTA A/B guarantee — bootloader only switches to the new slot after a full, validated write; an interrupted write never gets marked bootable |

**Desk-check verdict:** covered by ESP-IDF's own well-tested OTA
mechanism; this project doesn't override any of that safety behavior. See
[`README.md`](../README.md#security-considerations) for the (deliberate)
lack of image signature verification — this is a real limitation, not
resolved by this task.

## Cenário 8: Troca de idioma (i18n)

| Step | Expected | Code path |
|---|---|---|
| 1 (EN default) | Default language | `i18n.c`'s default `s_current_lang = I18N_LANG_EN` |
| 2-3 (switch PT/ES) | Immediate UI update, no functionality lost | `settings_hub.c`'s Language button cycles via `i18n_set_language()` + `nav_shell_refresh_labels()` + full rebuild of the current screen |

**Desk-check verdict — HONEST SCOPE CAVEAT (carried over from T055's own
notes):** only the navigation sidebar and the Config screen's own text are
currently i18n-driven end-to-end. Screens like the roast dashboard, manual
control, profile editor, and session history still use hardcoded English
strings. Scenario 8 as literally written ("Nenhuma funcionalidade é
perdida na troca de idioma" / interface reflects the language everywhere)
is **only partially satisfied** — no functionality is lost (nothing
breaks), but most screen text does not yet translate. This should be
called out to the user explicitly, not silently marked as fully passing.

## Overall summary

Of 8 scenarios (+5b), the large majority of individual expected behaviors
have a clear, directly-traceable code path verified by static reading of
the source. Known, honestly-documented gaps found during this desk check:

1. No on-device (display) trigger for the Manual/Artisan mode switch —
   web-dashboard-only today (Cenário 5).
2. `.alog` (Artisan native format) session export was never implemented —
   CSV only (Cenário 5b).
3. i18n coverage is partial — only nav sidebar + Config screen text,
   not a full per-screen retrofit (Cenário 8).
4. DTR%/RoR numerical correctness has not been cross-checked against a
   real roast or Artisan's own computed values (Cenário 2).
5. Artisan Modbus register exposure for manually-marked events was not
   freshly re-verified this session (Cenário 5, step 5).

None of these are safety-critical (Cenário 1, the mandatory scenario, has
no identified gaps). All require real hardware / a live Artisan session to
close out — they cannot be resolved through further static code review
alone.

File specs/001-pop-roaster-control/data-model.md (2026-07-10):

# Data Model: Pop Roaster Control Platform

## 1) RoastProfile

Descrição: Perfil reutilizável de torra com curva alvo e limites operacionais.

Campos:
- id (string, UUID)
- name (string, 1..64, obrigatório, único)
- description (string, 0..256)
- roastCurve (array de CurvePoint, obrigatório)
- maxHeaterPct (int, 0..100, obrigatório)
- preheatTargetC (float, opcional)
- developmentTargetPct (float, 0..100, opcional)
- dropCurvePointRef (referência opcional a um CurvePoint que dispara transição automática para resfriamento)
- createdAt (datetime)
- updatedAt (datetime)
- revision (int, >=1)

Regras de validação:
- roastCurve deve ter pelo menos 2 pontos ordenados por tempo.
- Não pode existir ponto com tempo negativo.
- targetFanPct de qualquer ponto da curva NÃO pode ser menor que o piso global fixo de 30% (constante de firmware, não pertence ao perfil).

Nota: `minFanPctDuringHeat` deixou de ser campo do perfil; o piso de ventilação durante aquecimento é uma constante global de firmware (30%), não configurável por perfil ou operador.

## 2) CurvePoint

Descrição: Ponto de referência de curva para controle guiado.

Campos:
- tSec (int, >=0)
- targetTempC (float, 20..350)
- targetFanPct (int, 0..100, opcional)
- targetHeaterPct (int, 0..100, opcional)

Regras de validação:
- tSec estritamente crescente dentro de roastCurve.
- targetTempC deve respeitar envelope de segurança do equipamento.

## 3) RoastSession

Descrição: Execução de torra de um lote, no Modo Perfil (vinculada a um perfil, com snapshot próprio) ou no Modo Manual/Artisan (sem perfil).

Campos:
- id (string, UUID)
- controlMode (enum: PROFILE, MANUAL_ARTISAN)
- profileId (string, nullable — referência ao perfil original, apenas informativa)
- profileSnapshot (object, nullable — cópia completa da curva/parâmetros do perfil no momento da execução; obrigatório quando controlMode = PROFILE)
- modeSwitchedAt (int64, nullable — tsMs em que a sessão trocou de PROFILE para MANUAL_ARTISAN, se aplicável)
- status (enum: IDLE, PREHEAT, ROASTING, DEVELOPMENT, COOLING, COMPLETED, ABORTED)
- startedAt (datetime)
- endedAt (datetime, nullable)
- operatorNote (string, 0..1024)
- currentSetpoints (object)
- safetyState (enum: OK, WARNING, TRIPPED)
- activeAlarmIds (array de string — alarmes críticos pendentes de reconhecimento manual)
- batchRecordId (string, nullable)
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

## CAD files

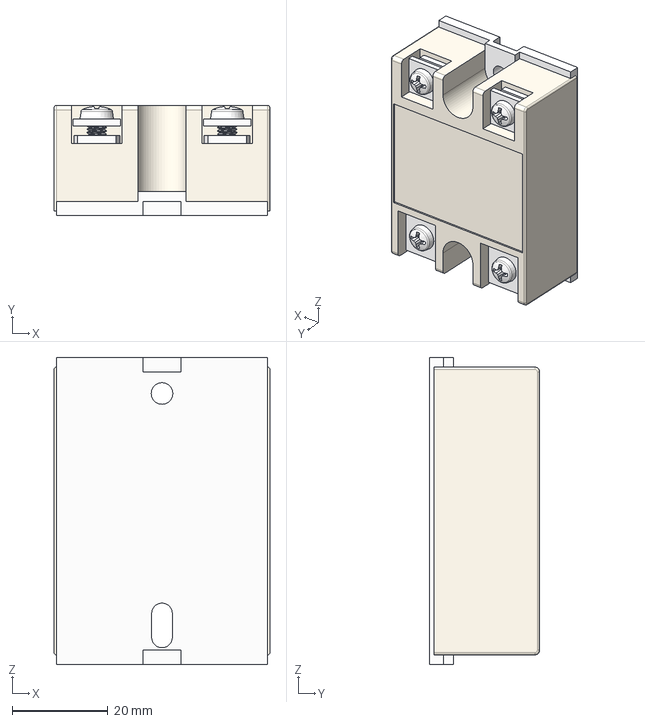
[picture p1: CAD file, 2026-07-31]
3D/my-b022/SSR-40 DD v4.step
45.0 x 23.0 x 64.0 mm
94017A250 x 2
94017A250(Mirror) x 2

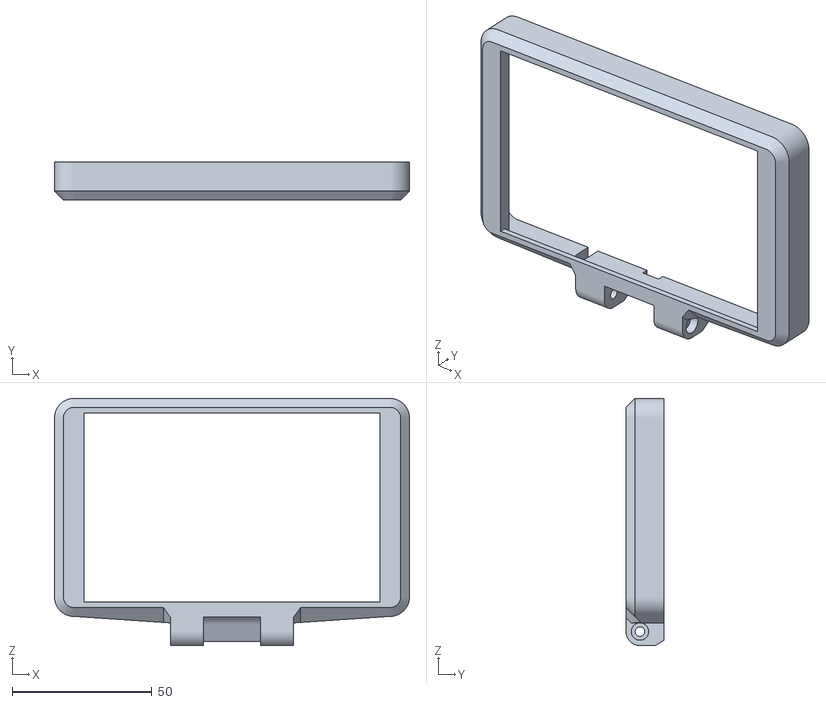
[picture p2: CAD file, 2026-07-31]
3D/my-b022/stl/display_case.stl
127.0 x 13.6 x 88.4

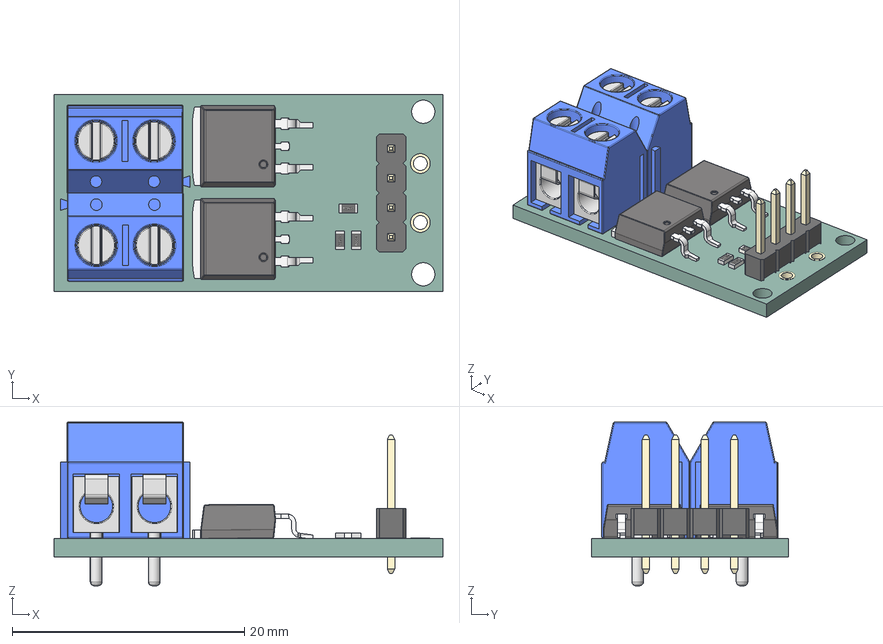
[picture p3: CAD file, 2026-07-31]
3D/my-b022/PWM Mosfet Modul 400W.step
33.5 x 17.0 x 14.1 mm
r-smd-0603 x 3
PinHeader
MOS x 2
tb5p-2p_p5_l10_w7-6_h10 v1 x 2

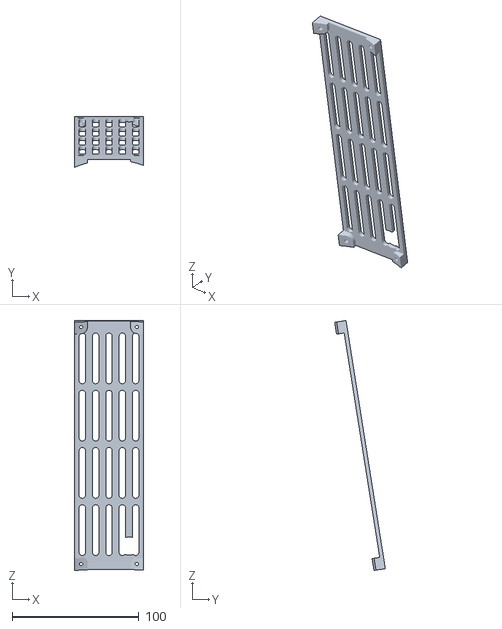
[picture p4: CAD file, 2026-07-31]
3D/my-b022/stl/internal.stl
54.0 x 40.0 x 197.0

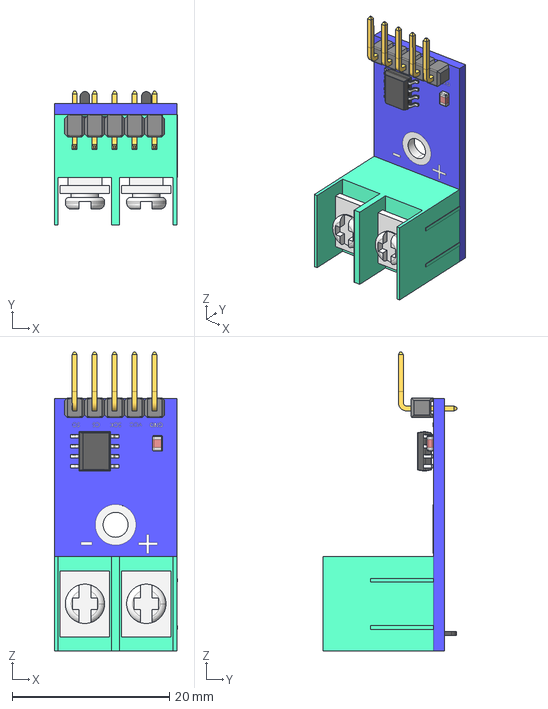
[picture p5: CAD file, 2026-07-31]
3D/my-b022/MAX6675 K type thermokoppel PCBA, header angle top.stp
15.7 x 17.0 x 38.0 mm

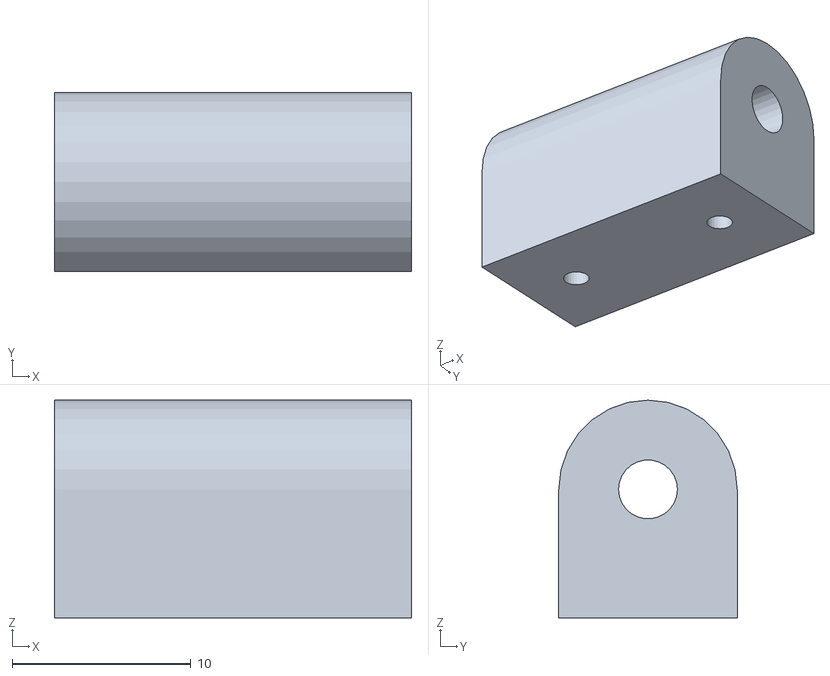
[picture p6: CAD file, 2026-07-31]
3D/my-b022/stl/ringe.stl
20.0 x 10.0 x 12.2

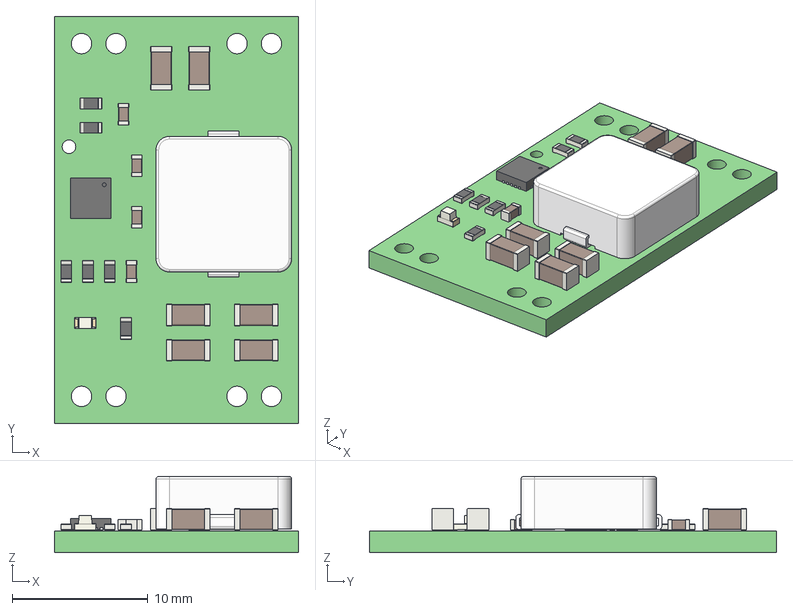
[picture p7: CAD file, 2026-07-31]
3D/my-b022/MINI560_light.step
18.0 x 30.0 x 5.62 mm
kicad_module_3D_MINI560 PCB

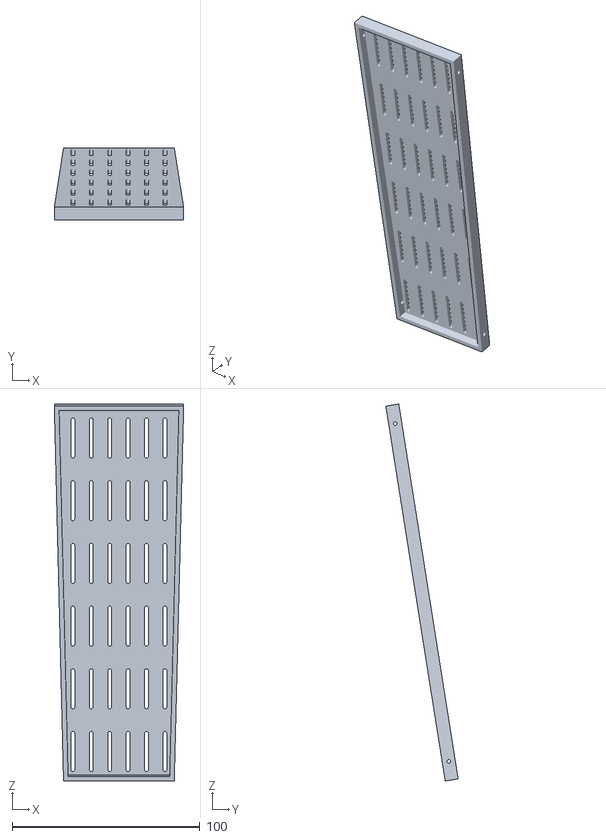
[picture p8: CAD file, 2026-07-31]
3D/my-b022/stl/cover.stl
68.9 x 38.5 x 200.8

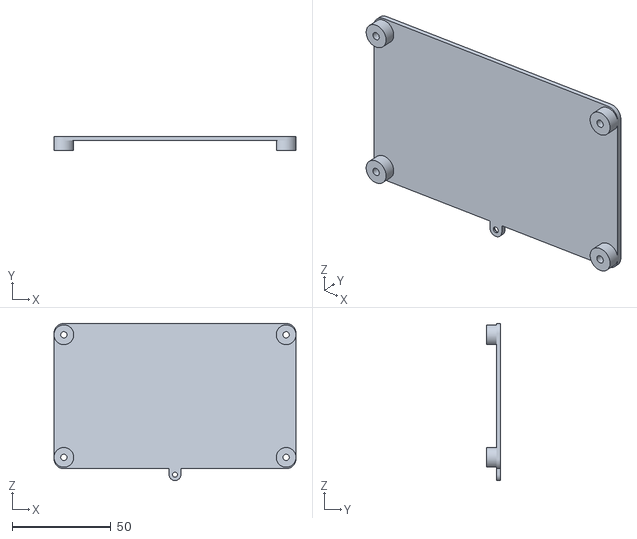
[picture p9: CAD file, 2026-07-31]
3D/my-b022/stl/display_case_cover.stl
122.6 x 6.95 x 79.6

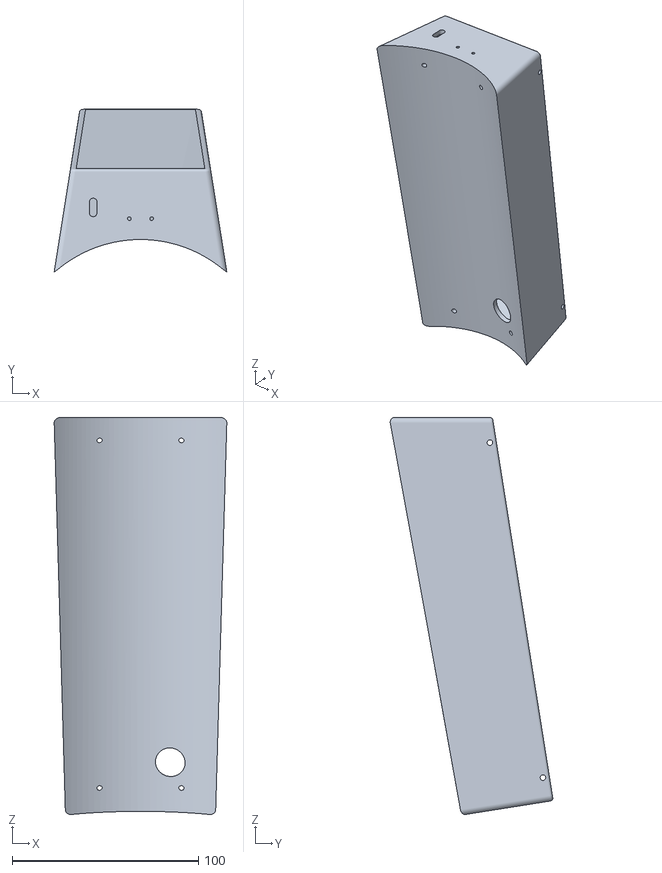
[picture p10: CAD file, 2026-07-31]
3D/my-b022/stl/support.stl
92.7 x 87.3 x 213.2

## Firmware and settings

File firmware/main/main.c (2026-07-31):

/**
 * @file main.c
 * @brief Pop Roaster firmware entry point.
 *
 * Boot sequence (see specs/001-pop-roaster-control/plan.md and research.md):
 *   1. Init NVS + storage layer (profiles, calibration, config, sessions).
 *   2. Init HAL drivers (MAX6675, SSR heater, fan PWM) using board_config.h pins.
 *   3. Init Safety Manager (must exist before any actuator can be commanded).
 *   4. Init display (esp_lcd_nv3041 + esp_lvgl_port) and touch (GT911).
 *   5. Init WiFi provisioning (AP+captive portal on first boot, else STA).
 *   6. Init HTTP/WebSocket server + Artisan adapter.
 *   7. Attempt session recovery (power-loss auto-resume, FR-022).
 *   8. Hand off to the UI/roast_core event loop.
 */
#include "esp_log.h"
#include "nvs_flash.h"

#include "storage/nvs_store.h"
#include "storage/session_store.h"
#include "storage/profile_store.h"
#include "hal/max6675.h"
#include "hal/ssr_heater.h"
#include "hal/fan_pwm.h"
#include "hal/wifi_provisioning.h"
#include "hal/touch_driver.h"
#include "hal/ota_manager.h"
#include "safety/safety_manager.h"
#include "safety/duration_watchdog.h"
#include "safety/fan_failure_detector.h"
#include "roast_core/session_state_machine.h"
#include "roast_core/command_dispatcher.h"
#include "roast_core/roast_telemetry_service.h"
#include "roast_core/profile_curve_follower.h"
#include "roast_core/pid_debug_log.h"
#include "roast_core/heater_pid.h"
#include "roast_core/session_recovery.h"
#include "web_api/server.h"
#include "artisan_adapter/artisan_bridge.h"
#include "ui_display/i18n.h"
#include "ui_display/display_panel.h"
#include "ui_display/widgets/nav_shell.h"
#include "ui_display/screens/roast_dashboard.h"
#include "ui_display/screens/manual_control.h"
#include "ui_display/screens/profile_list.h"
#include "ui_display/screens/session_review.h"
#include "ui_display/screens/settings_hub.h"


static const char *TAG = "pop_roaster_main";


void app_main(void)
{
    ESP_LOGI(TAG, "Pop Roaster booting...");

    /* NVS must be initialized before anything else touches flash storage. */
    esp_err_t nvs_ret = nvs_flash_init();
    if (nvs_ret == ESP_ERR_NVS_NO_FREE_PAGES || nvs_ret == ESP_ERR_NVS_NEW_VERSION_FOUND) {
        ESP_ERROR_CHECK(nvs_flash_erase());
        nvs_ret = nvs_flash_init();
    }
    ESP_ERROR_CHECK(nvs_ret);

    ESP_ERROR_CHECK(nvs_store_init());
    ESP_ERROR_CHECK(session_store_init());
    ESP_ERROR_CHECK(pid_debug_log_init());
    /* Restores any live-tuned PID gains saved from the web Diagnostics page,
     * before the follower starts driving the loop with them. */
    ESP_ERROR_CHECK(heater_pid_load_tuning());
    ESP_ERROR_CHECK(profile_store_init());
    ESP_ERROR_CHECK(i18n_init());

    /* Peripheral drivers - pins come from board_config.h (Kconfig-driven). */
    ESP_ERROR_CHECK(max6675_init());
    ESP_ERROR_CHECK(ssr_heater_init());
    ESP_ERROR_CHECK(fan_pwm_init());

    /* Safety Manager must be up before the state machine can accept commands. */
    ESP_ERROR_CHECK(safety_manager_init());
    ESP_ERROR_CHECK(session_state_machine_init());
    ESP_ERROR_CHECK(command_dispatcher_init());
    ESP_ERROR_CHECK(roast_telemetry_service_init());
    ESP_ERROR_CHECK(profile_curve_follower_init());
    ESP_ERROR_CHECK(duration_watchdog_init());
    ESP_ERROR_CHECK(fan_failure_detector_init());

    /* Display / touch bring-up (fixed board pins from board_config.h).
     * Touch failure is NOT fatal: the display/WiFi/web should still come up
     * even if the GT911 glitches on this boot (ui_display_panel_init()
     * already tolerates a missing touch handle). */
    esp_err_t touch_err = touch_driver_init();
    if (touch_err != ESP_OK) {
        ESP_LOGE(TAG, "touch_driver_init failed (continuing without touch): %s", esp_err_to_name(touch_err));
    }
    ESP_ERROR_CHECK(ui_display_panel_init());

    /* If the GT911 didn't answer above, touch_driver.c is now retrying in
     * the background - hook it up live if/when it succeeds instead of
     * requiring a reboot to pick it up. */
    touch_driver_set_ready_callback(ui_display_panel_attach_touch);

    /* Persistent left navigation sidebar (FR-045): register each tab's
     * content renderer before building the shell. Labels include a small
     * icon line (LV_SYMBOL_*) above the text, per the user's request. */
    nav_shell_register_tab(NAV_SHELL_TAB_ROAST, LV_SYMBOL_PLAY "\nRoast", roast_dashboard_show_in, roast_dashboard_hide);
    nav_shell_register_tab(NAV_SHELL_TAB_PRESETS, LV_SYMBOL_LIST "\nPresets", profile_list_show_in, profile_list_hide);
    nav_shell_register_tab(NAV_SHELL_TAB_MANUAL, LV_SYMBOL_TINT "\nManual", manual_control_show_in, manual_control_hide);
    nav_shell_register_tab(NAV_SHELL_TAB_HISTORY, LV_SYMBOL_DIRECTORY "\nHistory", session_review_show_in, session_review_hide);
    nav_shell_register_tab(NAV_SHELL_TAB_CONFIG, LV_SYMBOL_SETTINGS "\nConfig", settings_hub_show_in, settings_hub_hide);
    ESP_ERROR_CHECK(nav_shell_init(NAV_SHELL_TAB_ROAST));

    ESP_ERROR_CHECK(wifi_provisioning_init());
    ESP_ERROR_CHECK(web_api_server_init());
    ESP_ERROR_CHECK(artisan_bridge_init());

    /* T053: confirm this boot is healthy (core subsystems + web server all
     * came up) before cancelling any pending OTA rollback - if this line
     * is never reached (crash-loop right after an update), the bootloader
     * auto-reverts to the previous known-good partition on its own. */
    ESP_ERROR_CHECK(ota_manager_init());

    /* FR-022: attempt to resume a roast that was active before a power loss. */
    ESP_ERROR_CHECK(session_recovery_try_resume());

    ESP_LOGI(TAG, "Pop Roaster boot complete");
}

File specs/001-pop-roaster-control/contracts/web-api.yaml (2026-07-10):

openapi: 3.1.0
info:
  title: Pop Roaster Local API
  version: 0.1.0
  description: API local para monitoramento, controle e manutenção do torrador Pop Roaster.
servers:
  - url: http://poproaster.local
paths:
  /api/v1/system/status:
    get:
      summary: Estado geral do sistema
      responses:
        '200':
          description: Estado atual
          content:
            application/json:
              schema:
                $ref: '#/components/schemas/SystemStatus'
  /api/v1/control/command:
    post:
      summary: Envia comando operacional (com validação de safety)
      requestBody:
        required: true
        content:
          application/json:
            schema:
              $ref: '#/components/schemas/ControlCommand'
      responses:
        '202':
          description: Comando aceito
        '409':
          description: Comando bloqueado por regra de segurança
  /api/v1/profiles:
    get:
      summary: Lista perfis de torra
      responses:
        '200':
          description: Lista de perfis
    post:
      summary: Cria perfil
      requestBody:
        required: true
        content:
          application/json:
            schema:
              $ref: '#/components/schemas/RoastProfile'
      responses:
        '201':
          description: Perfil criado
  /api/v1/profiles/{profileId}:
    put:
      summary: Atualiza perfil
      parameters:
        - in: path
          name: profileId
          required: true
          schema:
            type: string
      requestBody:
        required: true
        content:
          application/json:
            schema:
              $ref: '#/components/schemas/RoastProfile'
      responses:
        '200':
          description: Perfil atualizado
    delete:
      summary: Exclui perfil
      parameters:
        - in: path
          name: profileId
          required: true
          schema:
            type: string
      responses:
        '204':
          description: Perfil excluído
  /api/v1/sessions/current:
    get:
      summary: Sessão de torra atual
      responses:
        '200':
          description: Sessão atual
  /api/v1/sessions/{sessionId}/export:
    get:
      summary: Exporta sessão concluída (CSV ou .alog do Artisan)
      parameters:
        - in: path
          name: sessionId
          required: true
          schema:
            type: string
        - in: query
          name: format
          required: true
          schema:
            type: string
            enum: [csv, alog]
      responses:
        '200':
          description: Arquivo exportado
  /api/v1/profiles/{profileId}/export:
    get:
      summary: Exporta perfil de torra em JSON
      parameters:
        - in: path
          name: profileId
          required: true
          schema:
            type: string
      responses:
        '200':
          description: Perfil em JSON
  /api/v1/profiles/import:
    post:
      summary: Importa perfil de torra a partir de arquivo JSON
      requestBody:
        required: true
        content:
          multipart/form-data:
            schema:
              type: object
              required: [file]
              properties:
                file:
                  type: string
                  format: binary
      responses:
        '201':
          description: Perfil importado
        '400':
          description: Arquivo de perfil inválido
  /api/v1/calibration/sensor:
    get:
      summary: Consulta offset de calibração atual do sensor
      responses:
        '200':
          description: Offset atual
    put:
      summary: Define/ajusta offset de calibração do sensor
      requestBody:
        required: true
        content:
          application/json:
            schema:
              $ref: '#/components/schemas/SensorCalibration'
      responses:
        '200':
          description: Calibração aplicada
  /api/v1/settings/language:
    put:
      summary: Define idioma da interface (display e web)
      requestBody:
        required: true
        content:
          application/json:
            schema:
              type: object
              required: [language]
              properties:
                language:
                  type: string
                  enum: [EN, PT, ES]
      responses:
        '200':
          description: Idioma atualizado
  /api/v1/peripherals/test:
    post:
      summary: Executa teste de periféricos
      requestBody:
        required: true
        content:
          application/json:
            schema:
              $ref: '#/components/schemas/PeripheralTestRequest'
      responses:
        '200':
          description: Resultado do teste
  /api/v1/firmware/upload:
    post:
      summary: Upload de firmware para OTA
      requestBody:
        required: true
        content:
          multipart/form-data:
            schema:
              type: object
              required: [file]
              properties:
                file:
                  type: string
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

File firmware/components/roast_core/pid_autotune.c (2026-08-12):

/**
 * @file pid_autotune.c
 * @brief Relay-feedback PID autotuner - see pid_autotune.h.
 */
#include <math.h>
#include <stdio.h>
#include <string.h>

#include "esp_log.h"
#include "esp_timer.h"

#include "hal/fan_pwm.h"
#include "roast_core/heater_pid.h"
#include "roast_core/pid_autotune.h"
#include "safety/safety_manager.h"

static const char *TAG = "pid_autotune";

#define AUTOTUNE_NOISEBAND_C 1.0f

/* General safety margin so a run can't climb indefinitely if something is
 * wrong - independent of any specific hardware protector. */
#define AUTOTUNE_OVERSHOOT_ABORT_C 25.0f
#define AUTOTUNE_TIMEOUT_S 2400
/* Operator-requested (2026-08-05): a real run (Pu=55.9s measured) took
 * ~22.5 minutes to finish because it never converged symmetrically and ran
 * all the way to the old cap of 40 phases. Halving it caps the same
 * worst case at roughly 20 phases * ~28s (half of Pu) =~ 9-10 minutes,
 * matching the requested ~10 min target - a well-converging (symmetric)
 * run still finishes far earlier than this on its own via
 * has_enough_data()+zc_symmetrical(), this only bounds the WORST case. */
#define AUTOTUNE_MAX_PHASES 20

/* ESPHome keeps 7 peak samples and needs 3 before it will compute. */
#define AUTOTUNE_PEAKS_MAX 7
#define AUTOTUNE_PEAKS_MIN 3
#define AUTOTUNE_ZC_MAX 16

typedef enum {
    RELAY_INIT,
    RELAY_POSITIVE,
    RELAY_NEGATIVE,
} relay_state_t;

static pid_autotune_state_t s_state = PID_AUTOTUNE_IDLE;
static float s_setpoint_c;
static uint8_t s_output_positive_pct;
static uint8_t s_output_negative_pct;
static uint8_t s_fan_pct_at_start;
static uint8_t s_cap_pct_at_start; /* Max Heater Power cap when the run started - see header note. */
static int64_t s_start_ms;
static int64_t s_end_ms; /* Frozen the instant the run stops - see get_status()'s elapsed_s. */
static char s_message[96];

static relay_state_t s_relay_state;
static uint32_t s_phase_count;

static relay_state_t s_freq_state;
static int64_t s_last_zc_ms;
static uint32_t s_zc_intervals_ms[AUTOTUNE_ZC_MAX];
static uint8_t s_zc_count;

static relay_state_t s_ampl_last_relay;
static float s_phase_min;
static float s_phase_max;
static float s_phase_mins[AUTOTUNE_PEAKS_MAX];
static float s_phase_maxs[AUTOTUNE_PEAKS_MAX];
static uint8_t s_phase_mins_n;
static uint8_t s_phase_maxs_n;

static float s_ku;
static float s_pu_s;

static void push_float(float *arr, uint8_t *n, float v)
{
    if (*n < AUTOTUNE_PEAKS_MAX) {
        arr[(*n)++] = v;
        return;
    }
    memmove(arr, arr + 1, (AUTOTUNE_PEAKS_MAX - 1) * sizeof(float));
    arr[AUTOTUNE_PEAKS_MAX - 1] = v;
}

static void reset_detectors(void)
{
    s_relay_state = RELAY_INIT;
    s_phase_count = 0;
    s_freq_state = RELAY_INIT;
    s_last_zc_ms = 0;
    s_zc_count = 0;
    s_ampl_last_relay = RELAY_INIT;
    s_phase_min = NAN;
    s_phase_max = NAN;
    s_phase_mins_n = 0;
    s_phase_maxs_n = 0;
    s_ku = 0.0f;
    s_pu_s = 0.0f;
}

static uint8_t relay_update(float error)
{
    if (s_relay_state == RELAY_INIT) {
        s_relay_state = (error > AUTOTUNE_NOISEBAND_C) ? RELAY_POSITIVE : RELAY_NEGATIVE;
    } else if (s_relay_state == RELAY_POSITIVE && error < -AUTOTUNE_NOISEBAND_C) {
        s_relay_state = RELAY_NEGATIVE;
        s_phase_count++;
    } else if (s_relay_state == RELAY_NEGATIVE && error > AUTOTUNE_NOISEBAND_C) {
        s_relay_state = RELAY_POSITIVE;
        s_phase_count++;
    }
    return (s_relay_state == RELAY_POSITIVE) ? s_output_positive_pct : s_output_negative_pct;
}

/* Crossings use a quarter of the relay's band so noise doesn't fake a period. */
static void frequency_update(int64_t now_ms, float error)
{
    const float band = AUTOTUNE_NOISEBAND_C / 4.0f;
    bool crossed = false;

    if (s_freq_state == RELAY_INIT) {
        s_freq_state = (error > band) ? RELAY_POSITIVE : RELAY_NEGATIVE;
    } else if (s_freq_state == RELAY_POSITIVE && error < -band) {
        s_freq_state = RELAY_NEGATIVE;
        crossed = true;
    } else if (s_freq_state == RELAY_NEGATIVE && error > band) {
        s_freq_state = RELAY_POSITIVE;
        crossed = true;
    }

    if (!crossed) {
        return;
    }
    if (s_last_zc_ms != 0) {
        uint32_t dt = (uint32_t)(now_ms - s_last_zc_ms);
        if (s_zc_count < AUTOTUNE_ZC_MAX) {
            s_zc_intervals_ms[s_zc_count++] = dt;
        } else {
            memmove(s_zc_intervals_ms, s_zc_intervals_ms + 1, (AUTOTUNE_ZC_MAX - 1) * sizeof(uint32_t));
            s_zc_intervals_ms[AUTOTUNE_ZC_MAX - 1] = dt;
        }
    }
    s_last_zc_ms = now_ms;
}

/* A peak always lands in the segment BEFORE the relay flips, so it is
 * recorded on the transition. */
static void amplitude_update(float error, relay_state_t relay_state)
{
    if (relay_state != s_ampl_last_relay) {
        if (s_ampl_last_relay == RELAY_POSITIVE) {
            push_float(s_phase_maxs, &s_phase_maxs_n, s_phase_max);
        } else if (s_ampl_last_relay == RELAY_NEGATIVE) {
            push_float(s_phase_mins, &s_phase_mins_n, s_phase_min);
        }
        s_phase_min = error;
        s_phase_max = error;
    }
    s_ampl_last_relay = relay_state;

    if (isnan(s_phase_min) || error < s_phase_min) {
        s_phase_min = error;
    }
    if (isnan(s_phase_max) || error > s_phase_max) {
        s_phase_max = error;
    }
}

static uint8_t peaks_available(void)
{
    return (s_phase_mins_n < s_phase_maxs_n) ? s_phase_mins_n : s_phase_maxs_n;
}

static float mean_oscillation_period_s(void)
{
    if (s_zc_count == 0) {
        return 0.0f;
    }
    float sum = 0.0f;
    for (uint8_t i = 0; i < s_zc_count; i++) {
        sum += (float)s_zc_intervals_ms[i];
    }
    /* Two crossings per full period. */
    return (sum / (float)s_zc_count) / 1000.0f * 2.0f;
}

static float mean_oscillation_amplitude(void)
{
    uint8_t n = peaks_available();
    if (n < 2) {
        return 0.0f;
    }
    float total = 0.0f;
    uint8_t count = 0;
    for (uint8_t i = 1; i + 1 < n; i++) {
        total += fabsf(s_phase_maxs[i] - s_phase_mins[i + 1]);
        count++;
    }
    if (count == 0) {
        return 0.0f;
    }
    return (total / (float)count) / 2.0f;
}

static bool zc_symmetrical(void)
{
    if (s_zc_count == 0) {
        return false;
    }
    uint32_t max_i = s_zc_intervals_ms[0];
    uint32_t min_i = s_zc_intervals_ms[0];
    for (uint8_t i = 0; i < s_zc_count; i++) {
        if (s_zc_intervals_ms[i] > max_i) {
            max_i = s_zc_intervals_ms[i];
        }
        if (s_zc_intervals_ms[i] < min_i) {
            min_i = s_zc_intervals_ms[i];
        }
    }
    return max_i > 0 && ((float)min_i / (float)max_i) >= 0.66f;
}
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

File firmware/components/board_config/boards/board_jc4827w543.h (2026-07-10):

/**
 * @file board_jc4827w543.h
 * @brief Fixed hardware definitions for the Guition JC4827W543 display board.
 *
 * Sources (see specs/001-pop-roaster-control/research.md Decision 2 for
 * full references and rationale):
 *   - https://github.com/lsdlsd88/JC4827W543 (factory documentation)
 *   - https://github.com/profi-max/JC4827W543_4.3inch_ESP32S3_board
 *     (community pinout + confirmed GT911 touch wiring)
 *
 * These pins are FIXED by the board's own PCB (display + touch are soldered
 * on-board) and must NOT be exposed via Kconfig - unlike the external
 * peripheral pins (MAX6675/SSR/fan), which are user-wired via the JST1.25
 * expansion connectors and configured in ../include/board_config.h.
 */
#pragma once

#define BOARD_MCU_NAME              "ESP32-S3-WROOM-1-N4R8"
#define BOARD_PSRAM_MB              8   /* Octal PSRAM (OSPI) */
#define BOARD_FLASH_MB              4   /* QSPI flash */

/* ---------------------------------------------------------------------
 * Display panel: NV3041A, 480x272, 16-bit RGB565, 4-wire QSPI interface.
 * ------------------------------------------------------------------- */
#define BOARD_DISPLAY_DRIVER_NAME   "NV3041A"
#define BOARD_DISPLAY_WIDTH_PX      480
#define BOARD_DISPLAY_HEIGHT_PX     272
#define BOARD_DISPLAY_ROTATION      0
#define BOARD_DISPLAY_BUS_TYPE      BOARD_DISPLAY_BUS_QSPI

#define BOARD_DISPLAY_PIN_CS        45
#define BOARD_DISPLAY_PIN_SCK       47
#define BOARD_DISPLAY_PIN_D0        21
#define BOARD_DISPLAY_PIN_D1        48
#define BOARD_DISPLAY_PIN_D2        40
#define BOARD_DISPLAY_PIN_D3        39
#define BOARD_DISPLAY_PIN_RST       (-1) /* not wired on this board */
#define BOARD_DISPLAY_PIN_BACKLIGHT 1

/* ---------------------------------------------------------------------
 * Touch: GT911 capacitive touch controller over I2C.
 * ------------------------------------------------------------------- */
#define BOARD_TOUCH_CONTROLLER_NAME "GT911"
#define BOARD_TOUCH_BUS_TYPE        BOARD_TOUCH_BUS_I2C

#define BOARD_TOUCH_PIN_SCL         4
#define BOARD_TOUCH_PIN_SDA         8
#define BOARD_TOUCH_PIN_RST         38
#define BOARD_TOUCH_PIN_INT         3
#define BOARD_TOUCH_I2C_ADDR        0x5D /* GT911_SLAVE_ADDRESS1 */

/* ---------------------------------------------------------------------
 * JST1.25 expansion connectors (confirmed physical pinout, informational
 * only). Peripheral GPIO assignments below are NOT hardcoded here - they
 * are configurable via Kconfig (see ../Kconfig) so the user can tune them
 * to whichever expansion pins they choose to wire, without touching code.
 *
 *   P1: GND, RXD, TXD, +5V           (UART/power - not general GPIO)
 *   P2: IO46, IO9, IO14, IO5
 *   P3: IO6, IO7, IO15, IO16
 *   P4: GND, 3.3V, IO17, IO18
 *
 * Hardware note: IO46 is INPUT-ONLY on ESP32-S3 - never assign it to an
 * output signal (e.g. SSR or fan PWM). It is well suited to MAX6675 SO/MISO
 * (a read-only signal from the MCU's perspective), which is the default in
 * Kconfig.
 * ------------------------------------------------------------------- */

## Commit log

2026-07-10 Initial commit: PopRoaster ESP32-S3 coffee roaster firmware
    [partitions.csv]
2026-07-10 Complete Phase 7 polish tasks + web dashboard overhaul + mandatory Cooling profile redesign
    - T039/T040: profile export/import JSON endpoints
    - T049: on-device WiFi setup screen
    - T050/T051: peripheral test + sensor calibration screens
    - T052/T053/T054: OTA firmware update (upload, status, rollback-safe boot, web page)
    - T055: i18n catalogs (EN/PT/ES) + language switch, nav sidebar + Config screen localized
    - T056/T065: RoastEvent milestone marking (manual FC/SC start/end + automatic Turning Point/Cool Start) with chart markers on both live dashboard and history
    - T057: BatchRecord metadata form (coffee/origin/weight)
    - T058: security considerations documented in README
    - T059: telemetry/WS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
    [main.c, manual_control.c]
2026-07-28 Hardware bring-up fixes: Max Heater Power cap, 65% fan floor, fan soft-start, GPIO wiring fix
    - New operator-configurable Max Heater Power cap (0-100%, NVS-persisted), applied as the final clamp in safety_manager_request_heater_pct(); new Config-tab UI (heater_settings.c/.h).
    - Fan minimum operating duty raised 30% -> 65% (motor doesn't reliably spin below that): SAFETY_FAN_MIN_PCT_DURING_HEAT, ROAST_PROFILE_FAN_MIN_PCT, and a hardware-level clamp in fan_pwm_set_pct().
    - Fan soft-start: ramps smoothly over ~3s via LEDC fade when turning on from a full stop; instantaneous for speed changes/turn-off.
    - Manual Control screen now shows a live explanation of why the heater may not be respondin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
    [fan_pwm.c, fan_pwm.h, manual_control.c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]
2026-07-29 Discrete fan levels, PID overshoot/windup fix, Max Heater Power scaling, session-free Manual mode, override-detection fix
    - Fan control quantized to 5 discrete levels (60/70/80/90/100%); fan_pwm.c tracks a real-time interpolated ramp value (not just the target) so the heater-requires-fan-floor check can't pass before the fan physically spins up; soft-start reduced to 2s.
    - heater_pid.c: fixed integral windup causing the heater to stay pinned near 100% well past target during this drum's thermal lag (operator-reported burn risk) via back-calculation anti-windup + a hard 3C overshoot cutoff.
    - Max Heater Power changed from a ceiling clamp to a linear proportional power scale, matching operat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
    [fan_pwm.c, fan_pwm.h, manual_control.c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]
2026-07-29 Heater control: PID log mechanism, live tuning API, and thermal protector detection
    Data-driven rework of the heater control, validated against real logs
    captured on the machine (firmware/logs/*.csv, included).
    PID debug logging (roast_core/pid_debug_log.c):
    - One CSV row per control tick to /storage/pid_debug.csv, downloadable
    from the Diagnostics page. Rows carry the live kp/ki/kd so a tuning
    sweep stays analyzable offline.
    - Writes are queued to a priority-3 writer task that batch-drains inside
    a single open/close, with the file size cached in RAM. Previously this
    ran inline on the priority-22 esp_timer task and did two full LittleFS
    open/close cycles per second, starving the p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
    [pid_debug.csv, pid_debug_2.csv, pid_debug_3.csv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]
2026-07-31 PID autotune feature, fan level rework, touch recovery, safety hardening
    - New relay-feedback PID autotune (pid_autotune.c/h): Astrom-Hagglund relay
    method + Ziegler-Nichols, ported from ESPHome. Fully automatic on-device
    screen (Config > PID Autotune, informed-consent checkbox required) and
    web API (/api/pid_autotune). Auto-applies+saves the No-Overshoot gain set
    to NVS the instant a run converges, regardless of which UI is open.
    - Fan levels reworked from 5 (60/70/80/90/100%) to 3 (80/90/100%) - the two
    weakest levels couldn't fluidize a ~100g green charge. Safety fan floor
    and profile fan floor raised to 80% to match. profile_store_load() now
    migrates legacy stored profiles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
    [display_panel.c, fan_pwm.c, fan_pwm.h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]
2026-07-31 Add 3D design assets (my-b022): STEP/STL models and FreeCAD source
    [MAX6675 K type thermokoppel PCBA, header angle top.stp, MINI560_light.step, PWM Mosfet Modul 400W.step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]
2026-08-07 PID: remove obsolete thermal-protector observer, add setpoint ramping + D filter
    - heater_pid.c/.h: thermal-protector observer removed entirely (physical bimetallic thermostat it detected has been physically removed from the machine); real backstops (240C absolute cutoff, hard_overshoot_margin_c) are untouched.
    - Added setpoint_ramp_c_per_s (default 1.0 C/s) to fix a big instant Target Temp / PREHEAT step overshooting into the hard cutoff on the first approach; hard cutoff still compares against the real final target.
    - Added d_filter_tau_s (low-pass on the D term only) to reduce oscillation amplification from sensor lag/noise.
    - pid_autotune: setpoint 130C->150C (closer to real operating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
    [pid_debug_5.csv, pid_debug_6.csv, pid_debug_7.csv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]
2026-08-07 PID: compensate heater element's nonlinear duty response
    Operator-reported (hands-on): element barely heats below ~65% commanded duty, then gets progressively more aggressive near 100% - a real plant nonlinearity, not a control-loop artifact (ssr_heater.c'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
    heater_pid.c/.h: new live-tunable duty_curve_deadzone_pct (default 65.0) / duty_curve_gamma (default 2.0) fields + heater_pid_compensate_duty_pct(), remapping the PID's logical 0-100% output onto the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
    Applied only to closed-loop callers (profile_curve_follower.c's drive_heating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
    [pid_debug_10.csv]
2026-08-10 Profile temp ramp, two-stage Cancel + Next-segment skip, pause wall-clock timer, fan levels 90/95/100
    - roast_profile: target BT ramps linearly between segments (was flat step); segment 0 and trailing Cooling stay flat per feedback
    - command_dispatcher/session_state_machine: Cancel is two-stage during ROASTING/DEVELOPMENT (1st press -> COOLING, 2nd -> ABORTED); PREHEAT cancels immediately (fixes broken Cancel during PREHEAT)
    - new 'Next segment' skip (session_sm_skip_curve_time / profile_curve_follower_skip_to_next_segment) advances the curve without affecting the displayed wall-clock timer
    - session_state_machine: new wall_elapsed_ms keeps ticking through pause for display; elapsed_ms (driv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
    [fan_pwm.c, fan_pwm.h, manual_control.c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]
2026-08-12 PID ramp feedforward, debug-log enable/disable toggle, min-on-floor doc fix, BoM
    [BoM.xlsx, pid_debug_11.csv]
2026-08-12 Add project README with BOM, remove xlsx/ods BOM files
    [BoM.xlsx]
2026-09-02 Fix Roast tab showing stale/edited profile curve for a finished roast
    roast_dashboard.c now loads the frozen per-roast profile snapshot (session_meta_t, same source Roast History uses) whenever displaying an already-started session (active or just completed/aborted), instead of always re-reading whatever preset is currently selected. Prevents a completed roast's dashed target curve from silently changing if the profile is edited/switched afterward, which caused Live and History to render the same roast differently.
2026-10-22 docs: update READMEs, add BOM, wiring diagram and images
2026-10-22 docs: update BOM links, remove prices, add project description
2026-10-22 Add LCD screenshot endpoint and Screen Capture web page; stop manual PID running with no target
2026-10-22 Sensor dropout hold, chart/session review fixes, 3D updates; release step replaces existing release
